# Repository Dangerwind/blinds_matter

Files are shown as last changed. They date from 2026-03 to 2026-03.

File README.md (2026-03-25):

Была задумка сделать устройство которое само поднимало/опускало бы рулонные шторы и интегрировалось в умный дом.

# ESP32 Blinds Controller with Matter

Контроллер рулонных штор на ESP32-WROOM-32 с интеграцией в умный дом через Matter (Алиса, Home Assistant, Apple Home, Google Home).

---

Как поднимаются шторы

Устройство можно собрать на базе отладочной платы ESP32 (проще, но не компактно) или на модуле ESP32-WROOM-32 (как на фото).

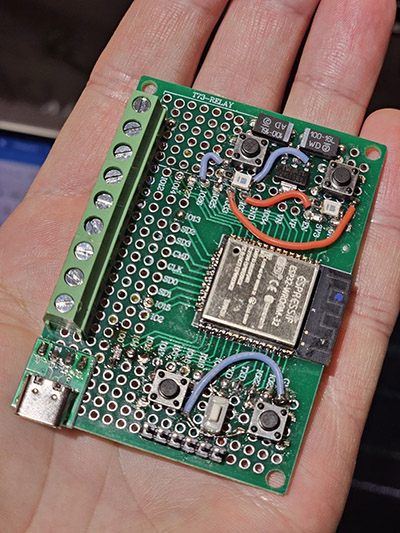
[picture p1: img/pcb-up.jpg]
Внешний вид, передняя часть

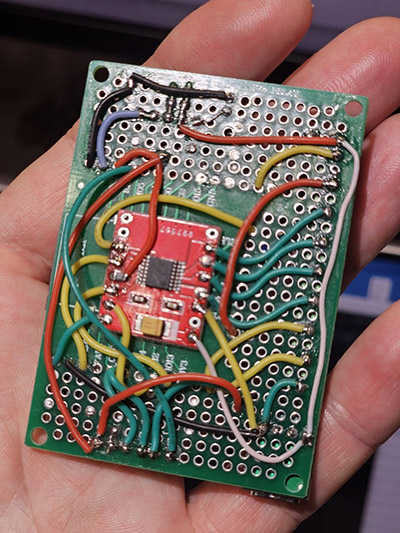
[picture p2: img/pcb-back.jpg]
Внешний вид, задняя часть


Производство печатной платы дорого для разового проекта, поэтому всё собрано на макетке.

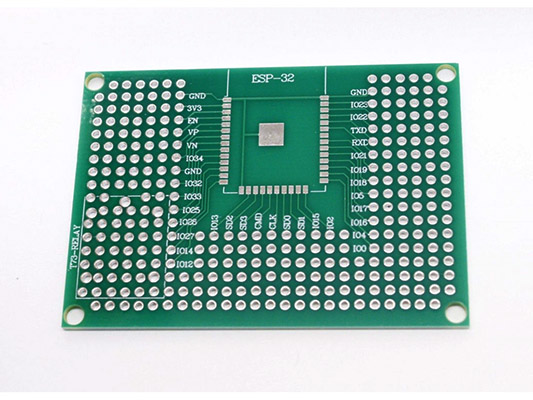
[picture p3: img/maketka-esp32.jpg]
Макетка для ESP32


---

## Список компонентов

| Компонент | Кол-во |
|---|---|
| Модуль ESP32-WROOM-32 | 1 |
| Тактовые кнопки IT-1102W (или любые другие) | 5 |
| Макетная плата для ESP32 5×7 см | 1 |
| Клеммник винтовой DG127-5.08-03P | 3 |
| Светодиоды SMD (любые, я использовал зелёные) | 2 |
| Резистор SMD 0805 2–3 кОм (для светодиодов) | 2 |
| Резистор SMD 0805 10 кОм (подтяжка ESP32) | 2 |
| Резистор SMD 0805 47 кОм (для DRV8833 nSLEEP) | 1 |
| Разъём PLS-6 (для программатора) | 1 |
| Плата DRV8833 | 1 |
| Конденсатор танталовый 100 мкФ 16В | 2 |
| Мотор-редуктор 6В 50 об/мин | 2 |
| Геркон нормально разомкнутый | 4 |
| Разъём Type-C на плате | 1 |
| Провод КСПВ 8×0.4 | по длине |
| Магниты (крепятся на нижний край шторы) | 2 |

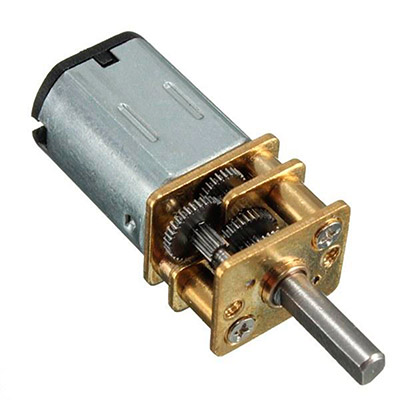
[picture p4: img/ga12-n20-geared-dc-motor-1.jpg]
Мотор-редуктор


> Если собираете на отладочной плате ESP32 — программатор не нужен, USB уже встроен.

---

## Схема включения

### Питание

Питание 5В подаётся через стабилизатор **ASM1117-3.3**, который даёт 3.3В для ESP32.

```
5В ──┬── [ASM1117-3.3] ──┬── 3.3В → ESP32, DRV8833 (логика)
     |                   |
   100мкФ             100мкФ
  (танталовый)       (танталовый)
     |                   |
    GND                 GND

5В также → VM пин DRV8833 (питание моторов)
```

---

### ESP32-WROOM-32 — обязательные подтяжки

> Если собираете на отладочной плате — эти резисторы уже установлены, ничего делать не нужно.

Для модуля ESP32-WROOM-32 без этих резисторов ESP32 не запустится или не будет прошиваться:

```
3.3В ──10кОм──── EN      (включение модуля)
3.3В ──10кОм──── GPIO0   (режим работы при старте)
```

---

### Светодиоды

```
GPIO25 ──2кОм──── LED1 (+) ──── LED1 (-) ──── GND
GPIO32 ──2кОм──── LED2 (+) ──── LED2 (-) ──── GND
```

---

### DRV8833 — драйвер моторов

**Питание:**

| Пин DRV8833 | Подключение |
|---|---|
| VM | +5В (питание моторов) |
| GND | GND |
| nSLEEP | 3.3В через резистор 47 кОм |

> Конденсатор 100 мкФ между VM и GND как можно ближе к модулю — защищает ESP32 от помех мотора.

**Управление от ESP32:**

| DRV8833 | GPIO ESP32 |
|---|---|
| AIN1 | GPIO 18 |
| AIN2 | GPIO 19 |
| BIN1 | GPIO 23 |
| BIN2 | GPIO 13 |

**Выходы на моторы:**

| DRV8833 | Назначение |
|---|---|
| AOUT1, AOUT2 | Мотор шторы 1 |
| BOUT1, BOUT2 | Мотор шторы 2 |

---

### Герконы

Нормально разомкнутые. Один провод на GPIO, второй на GND. Внутренняя подтяжка включается программно.

| GPIO | Назначение |
|---|---|
| GPIO 4 | Геркон шторы 1 — положение «вниз» |
| GPIO 16 | Геркон шторы 1 — положение «вверх» |
| GPIO 15 | Геркон шторы 2 — положение «вниз» |
| GPIO 27 | Геркон шторы 2 — положение «вверх» |

---

### Кнопки управления

Один провод на GPIO, второй на GND.

| GPIO | Кнопка |
|---|---|
| GPIO 26 | Шторы 1 — вверх |
| GPIO 17 | Шторы 1 — вниз |
| GPIO 33 | Шторы 2 — вверх |
| GPIO 22 | Шторы 2 — вниз |
| GPIO 21 | СТОП |

- **Короткое нажатие СТОП** — аварийная остановка всех моторов
- **Удержание СТОП 15 сек** — сброс привязки и переход в режим комиссионирования (оба LED мигают 4 раза в секунду до подключения к умному дому)

---

### Разъём подключения проводов (сверху вниз)

| Пин | Назначение |
|-----|---|
| 1 (верхний) | GPIO 27 — геркон «вверх» шторы 2 |
| 2 | GPIO 15 — геркон «вниз» шторы 2 |
| 3 | BOUT1 — мотор шторы 2 |
| 4 | BOUT2 — мотор шторы 2 |
| 5 | AOUT2 — мотор шторы 1 |
| 6 | AOUT1 — мотор шторы 1 |
| 7 | GPIO 16 — геркон «вверх» шторы 1 |
| 8 | GPIO 4 — геркон «вниз» шторы 1 |
| 9 (нижний) | GND — общий провод |

Герконы и моторы соединяются одним 8-жильным проводом КСПВ 8×0.4. Земля у всех герконов общая — один провод на все четыре. Хватает 8 жил, но можно взять КСПВ 10×0.4 в зависимости от прокладки кабеля.

---

### Разъём программатора

Вывести на разъём PLS-6:

| Пин | Назначение |
|-----|---|
| 1 | 3.3В |
| 2 | GND |
| 3 | TX → RX (GPIO3) ESP32 |
| 4 | RX → TX (GPIO1) ESP32 |
| 5 | RST → GPIO0 ESP32 (режим прошивки) |
| 6 | EN → EN ESP32 (сброс) |

---

## Matter комиссионирование

Параметры устройства (задаются в `CHIPDeviceConfig.h`):
- discriminator: **4001**
- passcode: **20202021**

Получить QR код:
```bash
python3 ~/esp/esp-matter/connectedhomeip/connectedhomeip/src/setup_payload/python/generate_setup_payload.py \
    -d 4001 -p 20202021 -vid 65521 -pid 32768 -cf 0 -dm 2
```

Или сгенерировать QR по ссылке: `https://project-chip.github.io/connectedhomeip/qrcode.html` — вставить код вида `MT:Y.K90.......`

**Добавление в Home Assistant:** Настройки → Устройства и службы → Matter (BETA) → Добавить устройство → QR код или ручной код.

---

## Установка и сборка

### 1. Установить зависимости

```bash
# ESP-IDF v5.1.4
git clone --recursive https://github.com/espressif/esp-idf.git ~/esp/esp-idf
cd ~/esp/esp-idf && git checkout v5.1.4 && ./install.sh
. ~/esp/esp-idf/export.sh

# ESP-Matter v1.3
git clone --recursive https://github.com/espressif/esp-matter.git ~/esp/esp-matter
cd ~/esp/esp-matter && git checkout v1.3 && ./install.sh
. ~/esp/esp-matter/export.sh
```

### 2. Изменить discriminator (опционально)

Каждое устройство должно иметь уникальный discriminator:

```bash
# Найти строку CHIP_DEVICE_CONFIG_USE_TEST_SETUP_DISCRIMINATOR
# поменять значение на нужное в hex (например 4001 = 0xFA1)
nano ~/esp/esp-matter/connectedhomeip/connectedhomeip/src/include/platform/CHIPDeviceConfig.h
```

### 3. Клонировать и собрать проект

```bash
git clone https://github.com/Dangerwind/blinds_matter.git ~/esp/blinds_matter
cd ~/esp/blinds_matter
chmod +x build_fixed.sh
./build_fixed.sh
```

>  На macOS используйте `build_fixed.sh` вместо `idf.py build` из-за бага chip_gn.

### 4. Найти порт программатора

```bash
ls /dev/cu.*       # macOS → например /dev/cu.usbserial-110
ls /dev/ttyUSB*    # Linux
```

### 5. Прошить

```bash
esptool.py -p /dev/cu.usbserial-110 -b 460800 \
    --before default_reset --after hard_reset \
    write_flash \
    0x1000  build/bootloader/bootloader.bin \
    0x8000  build/partition_table/partition-table.bin \
    0x20000 build/blinds_matter.bin
```

### 6. Мониторинг

```bash
idf.py -p /dev/cu.usbserial-110 monitor
```

### 7. Полный сброс (при проблемах)

```bash
idf.py -p /dev/cu.usbserial-110 erase-flash
# затем повторить шаг 5
```

---

## Монтаж

Герконы крепятся сверху и снизу окна. Когда штора доходит краем до геркона (на нижнем крае шторы закреплён магнит), мотор автоматически останавливается.

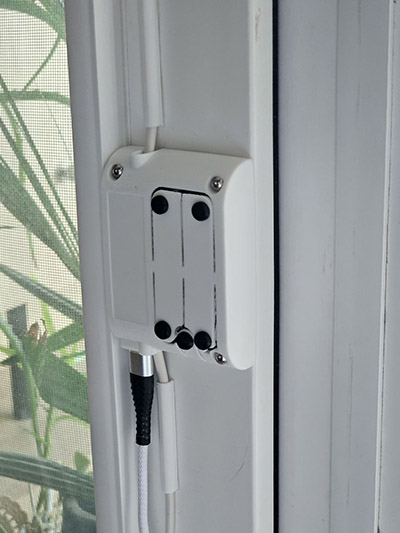
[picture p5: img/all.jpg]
Общий вид

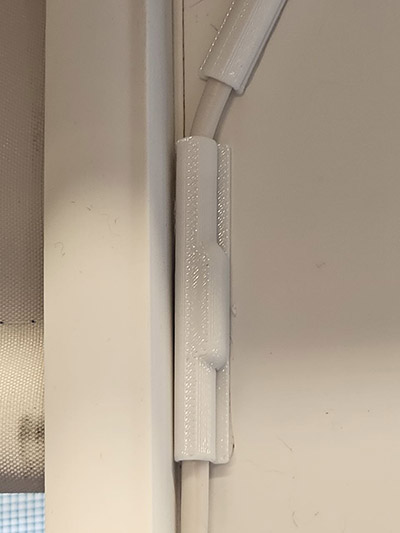
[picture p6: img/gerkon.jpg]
Крепление геркона

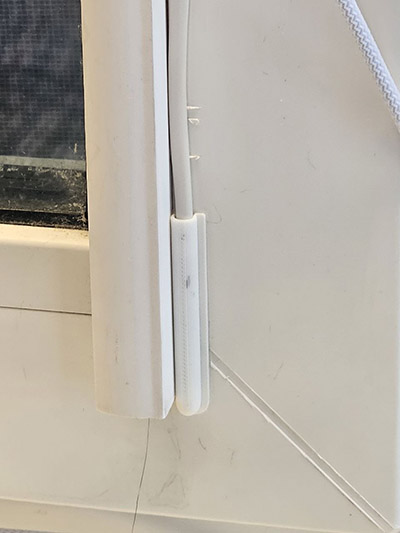
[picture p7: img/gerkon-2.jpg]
Крепление геркона 2

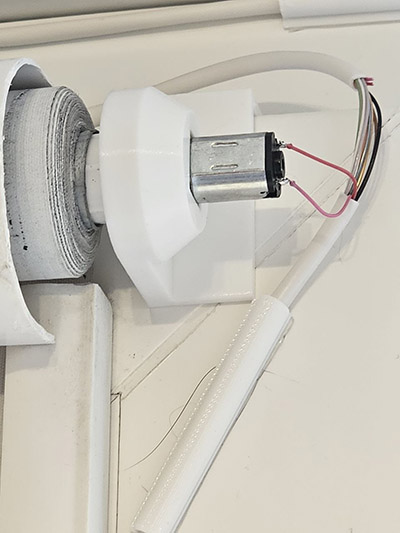
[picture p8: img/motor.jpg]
Крепление двигателя


Корпус устройства и все пластиковые детали напечатаны из PETG на 3D принтере. Все 3D модели в формате STL находятся в папке `STL`. В шторах нужно заменить механизм подъёма на напечатанный механизм с мотором.

---

*Весь код написан полностью с помощью ИИ.*

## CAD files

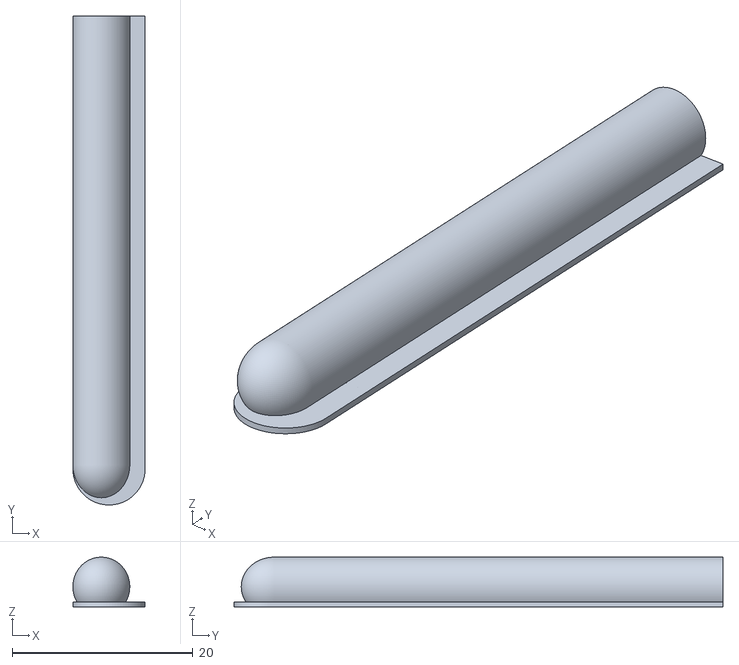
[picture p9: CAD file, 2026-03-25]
stl/support-gerkon.stl
8.00 x 54.1 x 5.50

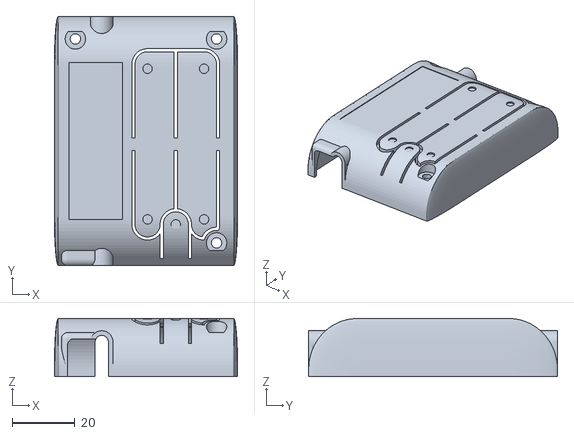
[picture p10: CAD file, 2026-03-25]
stl/box.stl
58.4 x 79.3 x 18.5

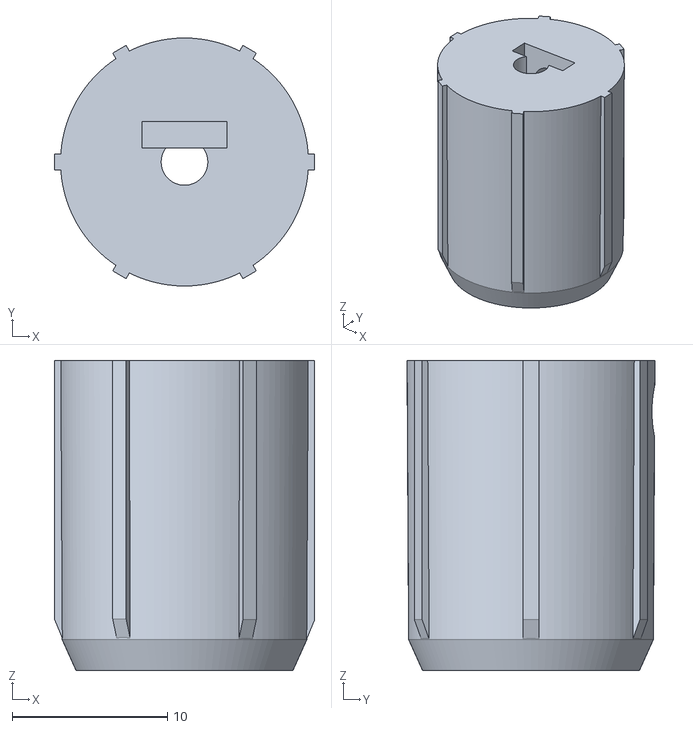
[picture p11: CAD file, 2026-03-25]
stl/roll-01.stl
16.8 x 16.0 x 20.0

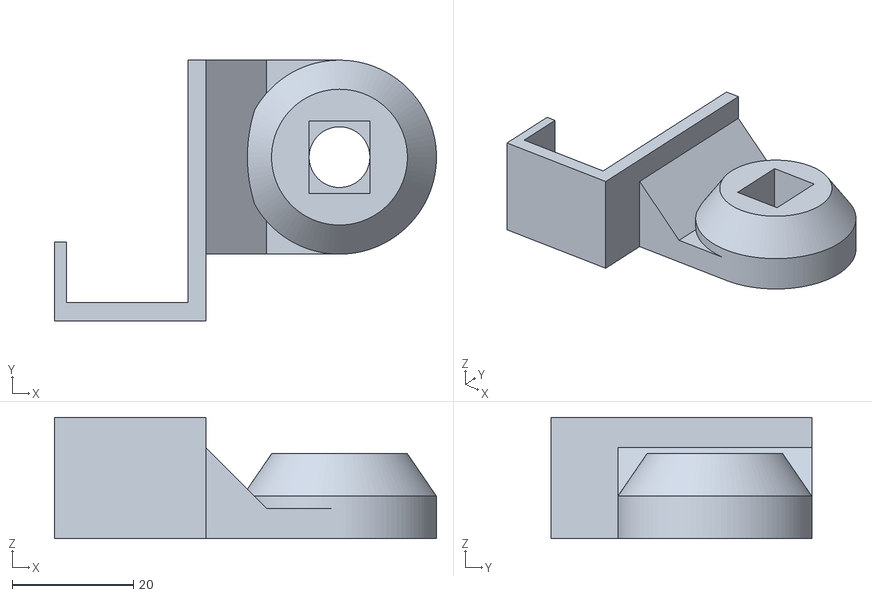
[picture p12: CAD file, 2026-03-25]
stl/motor-support.stl
63.0 x 43.0 x 20.0

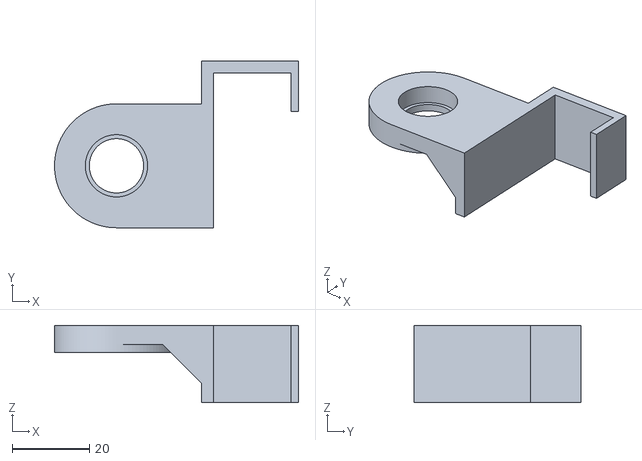
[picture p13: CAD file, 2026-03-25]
stl/next-support.stl
63.0 x 43.0 x 20.0

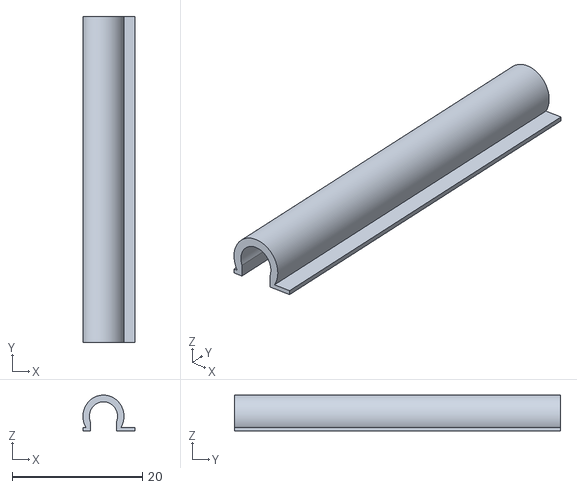
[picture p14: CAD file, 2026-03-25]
stl/support-01.stl
8.00 x 50.0 x 5.50

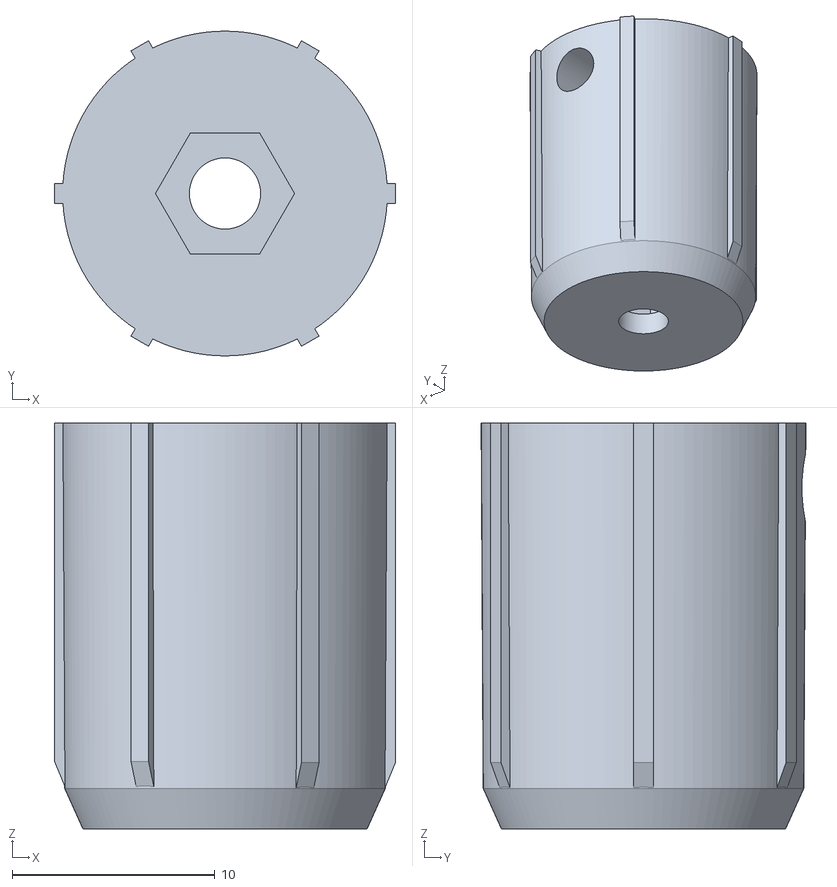
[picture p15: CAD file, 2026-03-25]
stl/roll-02.stl
16.8 x 16.0 x 20.0

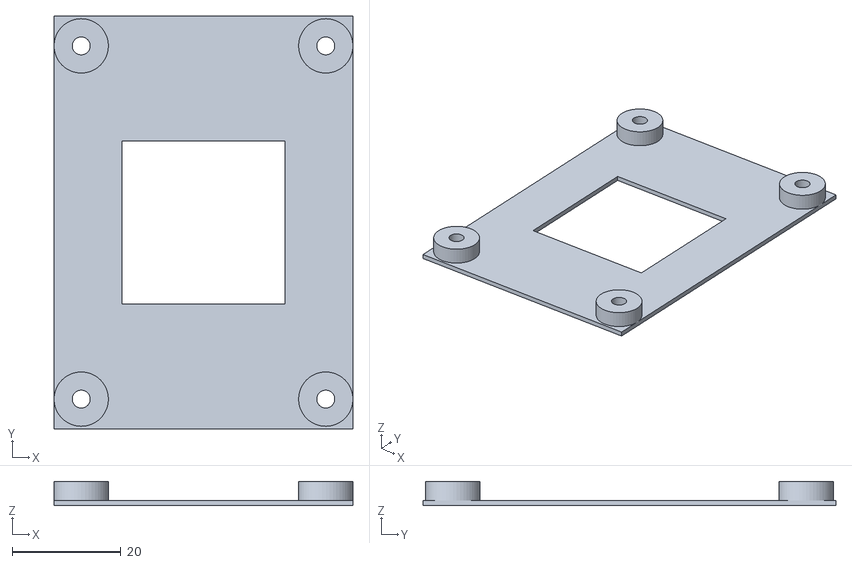
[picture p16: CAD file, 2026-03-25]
stl/box-back.stl
55.0 x 76.0 x 4.50

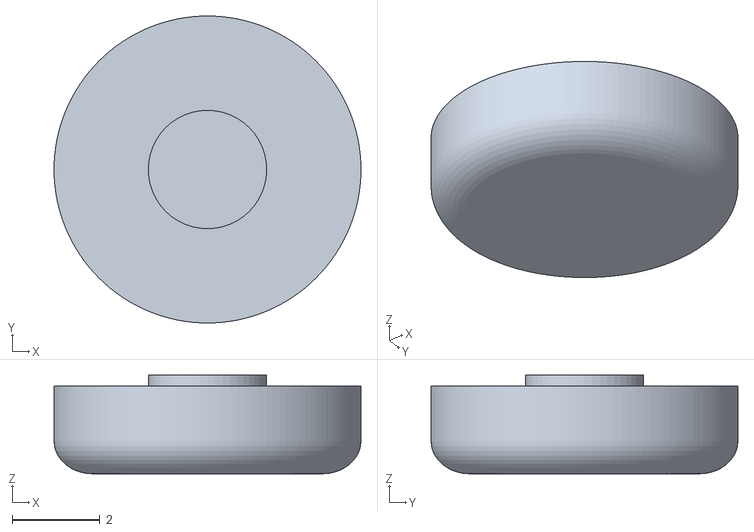
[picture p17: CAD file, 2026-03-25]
stl/button.stl
7.00 x 7.00 x 2.25

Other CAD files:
stl/support-gerkon2.stl

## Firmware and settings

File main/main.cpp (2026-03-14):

#include "motor_control.h"
#include "button_handler.h"
#include "matter_handler.h"

#include "freertos/FreeRTOS.h"
#include "freertos/task.h"
#include "esp_log.h"

static const char *TAG = "main";

static void on_motor_stopped(motor_channel_t channel)
{
    // Сообщить Matter что мотор остановился → переключатели в HA → OFF
    matter_report_motor_stopped(channel == MOTOR_CHANNEL_1 ? 1 : 2);
}

static void poll_task(void *arg)
{
    ESP_LOGI(TAG, "Poll task started");
    while (true) {
        button_handler_poll();
        motor_watchdog_tick();
        vTaskDelay(pdMS_TO_TICKS(10));
    }
}

extern "C" void app_main(void)
{
    ESP_LOGI(TAG, "ESP32 Blinds Controller — booting");

    motor_init();
    motor_set_stopped_callback(on_motor_stopped);
    button_handler_init();

    xTaskCreate(poll_task, "poll_task", 4096, nullptr, 5, nullptr);

    matter_handler_init();
    matter_handler_start();

    ESP_LOGI(TAG, "app_main complete");
}

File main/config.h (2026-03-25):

#pragma once
// ==============================================================================
// config.h
// Central configuration: GPIO pins, timing constants, Matter parameters
// ==============================================================================

#include "driver/gpio.h"

// ── Motor driver (DRV8833) pins ───────────────────────────────────────────────
// Each motor needs two pins: AIN1/AIN2 for motor 1, BIN1/BIN2 for motor 2
// Forward:  xIN1=HIGH, xIN2=LOW
// Reverse:  xIN1=LOW,  xIN2=HIGH
// Stop:     xIN1=LOW,  xIN2=LOW (coast)
#define MOTOR1_IN1   GPIO_NUM_18   // AIN1
#define MOTOR1_IN2   GPIO_NUM_19   // AIN2
#define MOTOR2_IN1   GPIO_NUM_23   // BIN1
#define MOTOR2_IN2   GPIO_NUM_13   // BIN2

// ── Limit switches (reed switches / gercons) ──────────────────────────────────
// Active LOW: switch pulls pin to GND when magnet is present (blinds at limit).
// Internal pull-up resistors are enabled in software.
#define LIMIT1_OPEN  GPIO_NUM_16   // Геркон 1 — шторы сверху
#define LIMIT1_CLOSE GPIO_NUM_4    // Геркон 1 — шторы внизу
#define LIMIT2_OPEN  GPIO_NUM_27   // Геркон 2 — шторы сверху
#define LIMIT2_CLOSE GPIO_NUM_15   // Геркон 2 — шторы внизу

// ── Control buttons ───────────────────────────────────────────────────────────
// Active LOW with internal pull-ups.
#define BUTTON1_OPEN    GPIO_NUM_26   // Кнопка 1 вверх
#define BUTTON1_CLOSE   GPIO_NUM_17   // Кнопка 1 вниз
#define BUTTON2_OPEN    GPIO_NUM_33   // Кнопка 2 вверх
#define BUTTON2_CLOSE   GPIO_NUM_22   // Кнопка 2 вниз
#define EMERGENCY_STOP  GPIO_NUM_21   // Кнопка Стоп

// ── Status LEDs ───────────────────────────────────────────────────────────────
// HIGH = LED on, LOW = LED off
#define LED1_STATUS  GPIO_NUM_25
#define LED2_STATUS  GPIO_NUM_32

// ── Watchdog timer ────────────────────────────────────────────────────────────
// Maximum time (ms) a motor may run before auto-stop if no limit switch fires.
#define MOTOR_WATCHDOG_MS   50000   // 15 seconds

// ── Button debounce ───────────────────────────────────────────────────────────
#define DEBOUNCE_MS         50      // ms to ignore bouncing after first edge

// ── Matter device identity ────────────────────────────────────────────────────
#define MATTER_VENDOR_ID    0xFFF1
#define MATTER_PRODUCT_ID   0x8001
#define MATTER_DEVICE_NAME  "Blinds Controller"

// ── Number of blinds channels ─────────────────────────────────────────────────
#define NUM_CHANNELS        2

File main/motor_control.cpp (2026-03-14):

// ==============================================================================
// motor_control.cpp
// Motor driver logic for MX1508 dual H-bridge module.
//
// MX1508 truth table per channel:
//   IN1=0, IN2=0 → Stop (coast)
//   IN1=1, IN2=0 → Forward (OPEN direction)
//   IN1=0, IN2=1 → Reverse (CLOSE direction)
//   IN1=1, IN2=1 → Brake (avoid — can damage driver)
// ==============================================================================

#include "motor_control.h"
#include "config.h"

#include "driver/gpio.h"
#include "freertos/FreeRTOS.h"
#include "freertos/task.h"
#include "esp_log.h"

static const char *TAG = "motor";

// ── Internal per-channel hardware mapping ─────────────────────────────────────
typedef struct {
    gpio_num_t in1;           // Motor driver IN1 pin
    gpio_num_t in2;           // Motor driver IN2 pin
    gpio_num_t limit_open;    // Reed switch — open limit
    gpio_num_t limit_close;   // Reed switch — close limit
    gpio_num_t led;           // Status LED
} motor_hw_t;

// Hardware pin assignment for each channel
static const motor_hw_t s_hw[NUM_CHANNELS] = {
    {   // Channel 0 — Blinds 1
        .in1         = MOTOR1_IN1,
        .in2         = MOTOR1_IN2,
        .limit_open  = LIMIT1_OPEN,
        .limit_close = LIMIT1_CLOSE,
        .led         = LED1_STATUS
    },
    {   // Channel 1 — Blinds 2
        .in1         = MOTOR2_IN1,
        .in2         = MOTOR2_IN2,
        .limit_open  = LIMIT2_OPEN,
        .limit_close = LIMIT2_CLOSE,
        .led         = LED2_STATUS
    }
};

// Runtime state for each channel
static motor_state_t s_state[NUM_CHANNELS] = {};
static motor_stopped_cb_t s_stopped_cb = nullptr;

void motor_set_stopped_callback(motor_stopped_cb_t cb) { s_stopped_cb = cb; }

// ── Internal helpers ──────────────────────────────────────────────────────────

/**
 * Read a limit switch state.
 * Switches are active LOW (pull-up enabled): returns true when triggered (GND).
 */
static inline bool _limit_active(gpio_num_t pin)
{
    return (gpio_get_level(pin) == 0);
}

/**
 * Apply IN1/IN2 levels directly to the MX1508.
 */
static void _set_motor_pins(motor_channel_t ch, int in1, int in2)
{
    gpio_set_level(s_hw[ch].in1, in1);
    gpio_set_level(s_hw[ch].in2, in2);
}

/**
 * Cut power to motor and turn off status LED.
 * Updates internal state — does NOT log (callers log where appropriate).
 */
static void _stop_motor_hw(motor_channel_t ch)
{
    _set_motor_pins(ch, 0, 0);
    gpio_set_level(s_hw[ch].led, 0);
    s_state[ch].is_running = false;
    s_state[ch].direction  = MOTOR_DIR_STOP;
    if (s_stopped_cb) s_stopped_cb((motor_channel_t)ch);
}

// ── GPIO configuration ────────────────────────────────────────────────────────

void motor_init(void)
{
    ESP_LOGI(TAG, "Initialising motor GPIO");

    for (int ch = 0; ch < NUM_CHANNELS; ch++) {
        // ── Motor output pins ──────────────────────────────────────────────
        gpio_config_t out_cfg = {
            .pin_bit_mask = (1ULL << s_hw[ch].in1) | (1ULL << s_hw[ch].in2),
            .mode         = GPIO_MODE_OUTPUT,
            .pull_up_en   = GPIO_PULLUP_DISABLE,
            .pull_down_en = GPIO_PULLDOWN_DISABLE,
            .intr_type    = GPIO_INTR_DISABLE
        };
        gpio_config(&out_cfg);

        // Start in stopped state
        _set_motor_pins((motor_channel_t)ch, 0, 0);

        // ── Status LED output ──────────────────────────────────────────────
        gpio_config_t led_cfg = {
            .pin_bit_mask = (1ULL << s_hw[ch].led),
            .mode         = GPIO_MODE_OUTPUT,
            .pull_up_en   = GPIO_PULLUP_DISABLE,
            .pull_down_en = GPIO_PULLDOWN_DISABLE,
            .intr_type    = GPIO_INTR_DISABLE
        };
        gpio_config(&led_cfg);
        gpio_set_level(s_hw[ch].led, 0);

        // ── Limit switch inputs (active LOW, internal pull-up) ─────────────
        gpio_config_t lim_cfg = {
            .pin_bit_mask = (1ULL << s_hw[ch].limit_open) |
                            (1ULL << s_hw[ch].limit_close),
            .mode         = GPIO_MODE_INPUT,
            .pull_up_en   = GPIO_PULLUP_ENABLE,
            .pull_down_en = GPIO_PULLDOWN_DISABLE,
            .intr_type    = GPIO_INTR_DISABLE
        };
        gpio_config(&lim_cfg);

        // Initialise state struct
        s_state[ch] = (motor_state_t){};
    }

    ESP_LOGI(TAG, "Motor GPIO ready");
}

// ── Motor start ───────────────────────────────────────────────────────────────

void motor_start(motor_channel_t channel, motor_dir_t dir)
{
    if (channel >= NUM_CHANNELS) return;

    // Refresh limit switch state before acting
    bool at_open  = _limit_active(s_hw[channel].limit_open);
    bool at_close = _limit_active(s_hw[channel].limit_close);
    s_state[channel].at_open  = at_open;
    s_state[channel].at_close = at_close;

    // Refuse to move if already at the requested limit
    if (dir == MOTOR_DIR_OPEN && at_open) {
        ESP_LOGW(TAG, "Ch%d: already at OPEN limit — ignoring", channel + 1);
        return;
    }
    if (dir == MOTOR_DIR_CLOSE && at_close) {
        ESP_LOGW(TAG, "Ch%d: already at CLOSE limit — ignoring", channel + 1);
        return;
    }

    ESP_LOGI(TAG, "Ch%d: starting motor → %s",
             channel + 1, dir == MOTOR_DIR_OPEN ? "OPEN" : "CLOSE");

    // Drive MX1508 pins
    if (dir == MOTOR_DIR_OPEN) {
        _set_motor_pins(channel, 1, 0);   // IN1=H, IN2=L → forward
    } else {
        _set_motor_pins(channel, 0, 1);   // IN1=L, IN2=H → reverse
    }

    // Update state and start watchdog timer
    s_state[channel].is_running  = true;
    s_state[channel].direction   = dir;
    s_state[channel].start_tick  = xTaskGetTickCount();

    // Light up the status LED
    gpio_set_level(s_hw[channel].led, 1);
}

// ── Motor stop ────────────────────────────────────────────────────────────────

void motor_stop(motor_channel_t channel)
{
    if (channel >= NUM_CHANNELS) return;
    if (!s_state[channel].is_running) return;

    ESP_LOGI(TAG, "Ch%d: stopping motor", channel + 1);
    _stop_motor_hw(channel);
}

void motor_stop_all(void)
{
    ESP_LOGW(TAG, "EMERGENCY STOP — stopping all motors");
    for (int ch = 0; ch < NUM_CHANNELS; ch++) {
        _stop_motor_hw((motor_channel_t)ch);
    }
}

// ── State query ───────────────────────────────────────────────────────────────

const motor_state_t *motor_get_state(motor_channel_t channel)
{
    return &s_state[channel];
}

// ── Watchdog tick (call periodically from task) ───────────────────────────────
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

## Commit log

2026-03-14 ESP32 Matter blinds controller - initial commit
    [partitions.csv]
2026-03-25 Add Type-C connector to the parts list
2026-03-25 Fix typo in Type-C connector description
2026-03-25 Fix typo in README.md regarding ESP32 assembly
    Corrected a typo in the description of the device assembly options.
2026-03-25 Update ESP32-WROOM-32 resistor instructions
    Clarify resistor requirement for ESP32-WROOM-32.
2026-03-25 Modify ESP32 Blinds Controller description
    Updated the integration description to include Алиса.
